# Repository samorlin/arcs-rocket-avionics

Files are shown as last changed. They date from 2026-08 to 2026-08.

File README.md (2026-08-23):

# ARCS Rocket Avionics System & Flight Computer

Custom-designed, multi-sensor flight computer and high-g avionics bay built for the UK ARCS National Rocketry Competition. Led a 4-person avionics sub-team through complete system lifecycle: prototyping, PCB layout, firmware development, mechanical structural integration, and post-flight failure analysis.
<table border="0">
  <tr>
    <td align="center">
      
      <br>
      <sub><b>Initial Prototype</b> — Sensor suite breadboard</sub>
    </td>
  </tr>
</table>

---

## Technical Specifications
* **Microcontroller:** ESP32 (3.3V logic)
* **Sensors:** BMP390 Barometric Altimeter (I2C), MPU6050 6-Axis IMU (I2C), u-blox M10 GNSS Module
* **Data Storage:** MicroSD SPI Module logging at 100 Hz
* **Telemetry:** ExpressLRS (ELRS) 2.4GHz RF Link with independent 1S battery backup
* **Power Architecture:** 2S LiPo (8.4V nominal) stepped down via high-efficiency 3.3V switching buck regulator
* **Airframe Diameter Envelope:** <40 mm ID
<table border="0">
  <tr>
    <td width="50%" align="center">
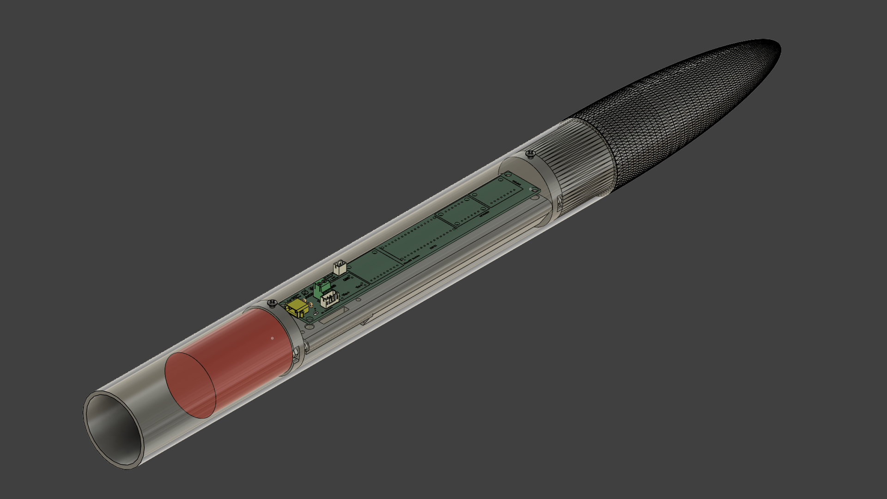
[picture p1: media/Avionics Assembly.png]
      
      <br>
      <sub><b>CAD Assembly</b> — Avionics bay & hardware stack</sub>
    </td>
---

## Key Hardware & Software Accomplishments

### 1. Custom 2-Layer PCB Design (KiCad)
* Designed a custom 2-layer FR4 board featuring dedicated ground planes to isolate sensitive I2C sensor traces from power supply EMI.
* Optimised trace routing and space efficiency to meet 40mm diameter envelope.
* Replaced low-vibration-tolerant Mini Tamiya power connectors with high-reliability XT30 connectors.
<table border="0">
  <tr>
    <td width="50%" align="center">
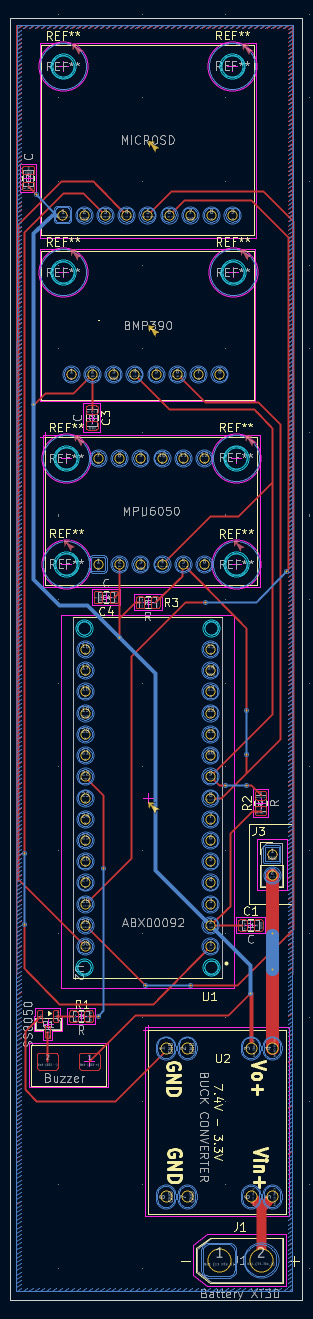
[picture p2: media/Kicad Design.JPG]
      
      <br>
      <sub><b>Initial PCB Design</b> — Unnecessary pull-up resistors and decoupling capacitors and too wide</sub>
    </td>
    <td width="50%" align="center">
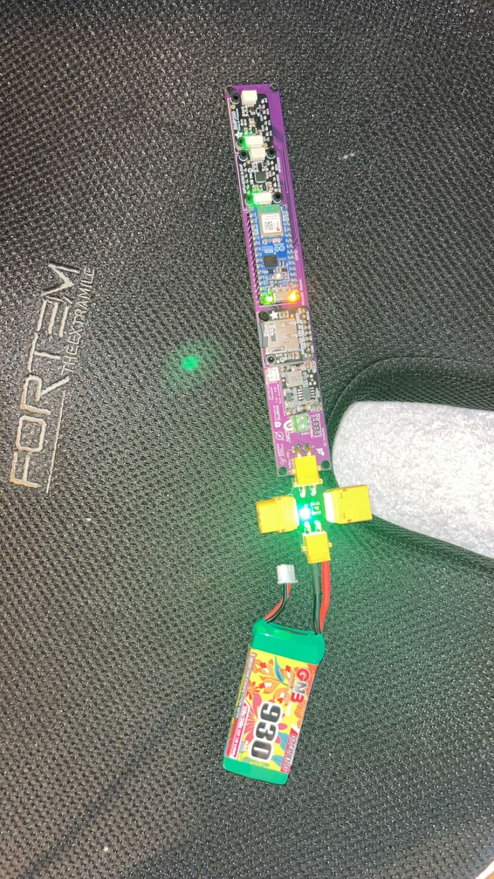
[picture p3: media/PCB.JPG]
      
      <br>
      <sub><b>Final Assembly</b> — Optimised tracing and stable power delivery and thinner package</sub>
    </td>
  </tr>
</table>

### 2. Mechanical Integration & Structural DFAM
* Designed a 3D-printed PETG sled featuring embedded brass heat-set inserts for secure, repeatable PCB mounting.
* Ran continuous M3 stainless steel load-bearing rods with Nyloc nuts through the sled assembly to absorb longitudinal shock forces during parachute deployment and ground impact.
* Designed battery mounting solution into the sled and added insert holes for live telemetry and LCD circuit.

### 3. Data Pipeline & Telemetry
* Developed C++ firmware for high-rate sensor sampling and continuous CSV write protocols.
* Created a Python script to push log data automatically into a MySQL database for MATLAB post-flight analysis and trajectory simulation.

---

## Flight Outcome & Crash Survivability Test
During competition testing, the vehicle achieved a measured apogee of 411 m. Due to a mechanical recovery wadding jam, the airframe failed to separate, resulting in an un-deployed ballistic descent hitting the ground at **80 m/s (~180 mph)**.

* **Result:** While the outer airframe and nosecone suffered heavy structural failure, the internal PETG sled and load-bearing steel rods fully protected the internal electronics.
* **Data Status:** The PCB remained intact, powered on, and actively logging. **100% of flight log data was recovered uncorrupted.**
<table border="0">
  <tr>
    <td width="50%" align="center">
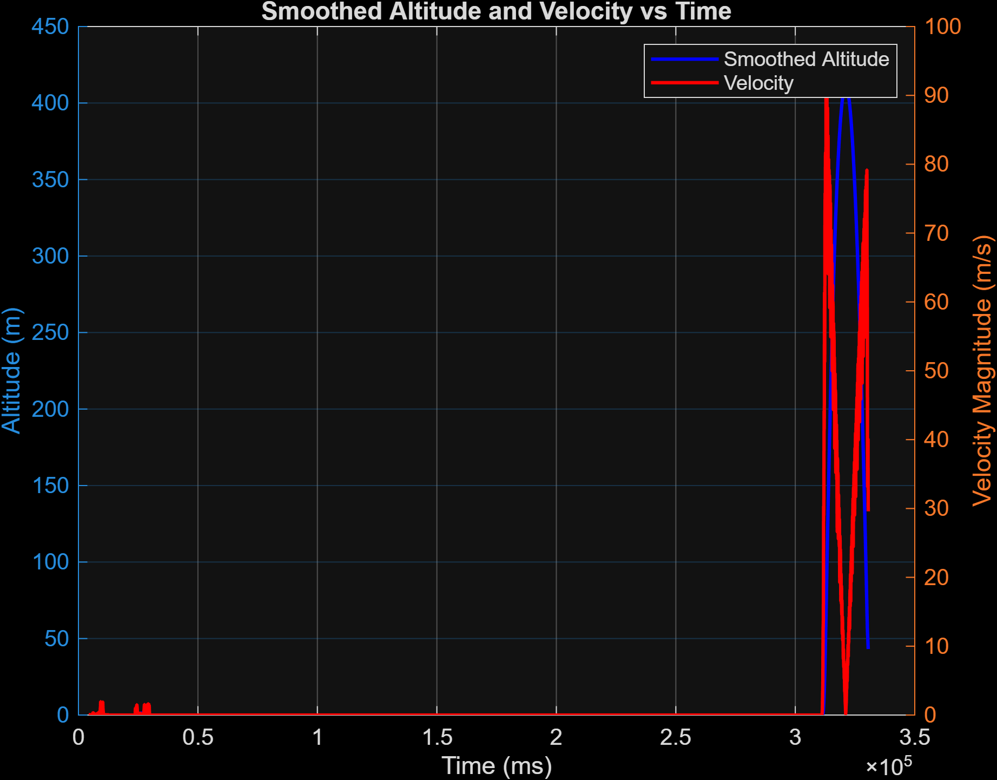
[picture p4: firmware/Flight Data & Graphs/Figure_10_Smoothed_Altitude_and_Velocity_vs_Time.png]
      
      <br>
      <sub><b>Altitude vs Time </b> — Graph shows 80m/s impact.</sub>
    </td>
    <td width="50%" align="center">
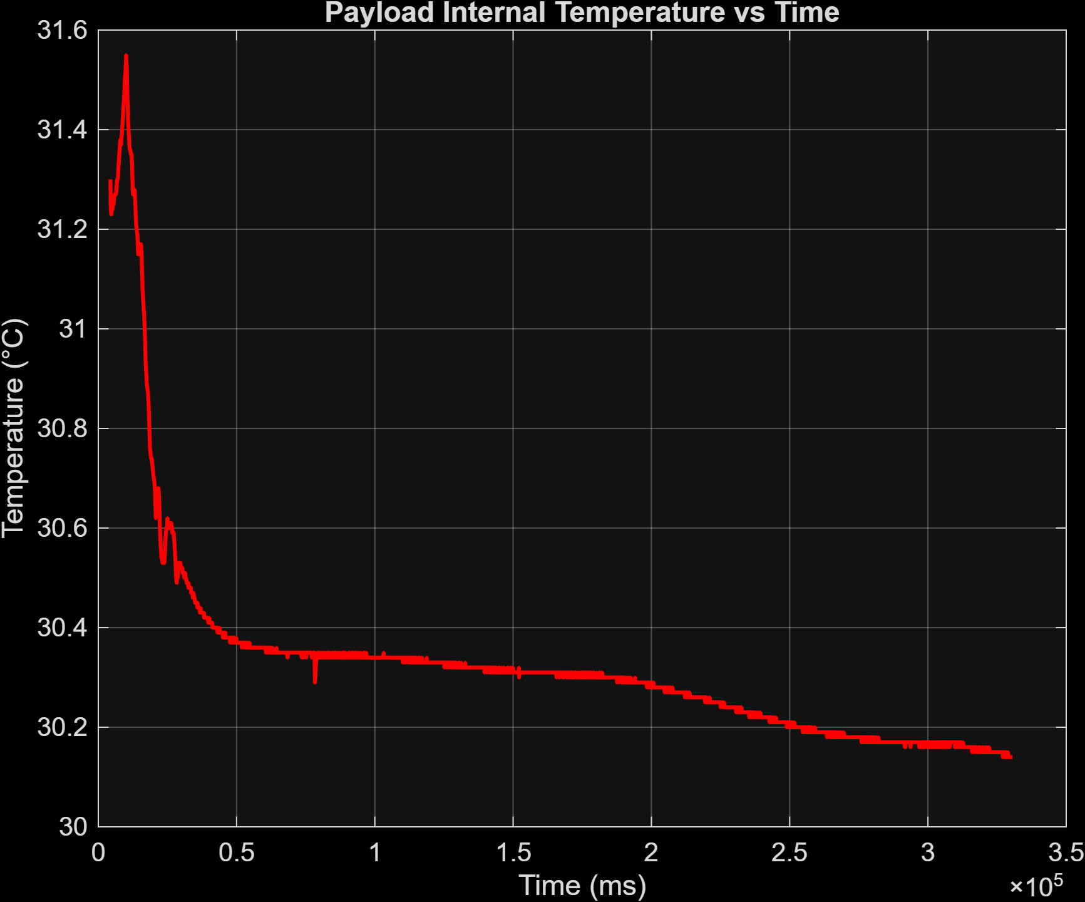
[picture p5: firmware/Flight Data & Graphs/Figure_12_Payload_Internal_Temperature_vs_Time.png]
      
      <br>
      <sub><b>Temperature vs Time</b> — Graph shows internal temperature spike when avionics powers on.</sub>
    </td>
  </tr>
</table>
---

## Repository Contents
* `/documentation/` - Formal milestone review PDFs (Critical Design Review, Manufacturing & Testing Review, Flight Readiness Review, Post-Flight Analysis).
* `/hardware/` - KiCad schematics, board layouts, Gerber files, and Full Avionics CAD Assembly (STEP).
* `/firmware/` - ESP32 C++ flight code, MATLAB scripts, raw sensor data csv and MATLAB plots.
* `/media/` - Hardware photos, PCB assembly images, Launch day photos, and post-flight recovery photos.

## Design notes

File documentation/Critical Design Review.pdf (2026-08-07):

# Critical Design Review

## Electric dysfunction Arcs Team 1

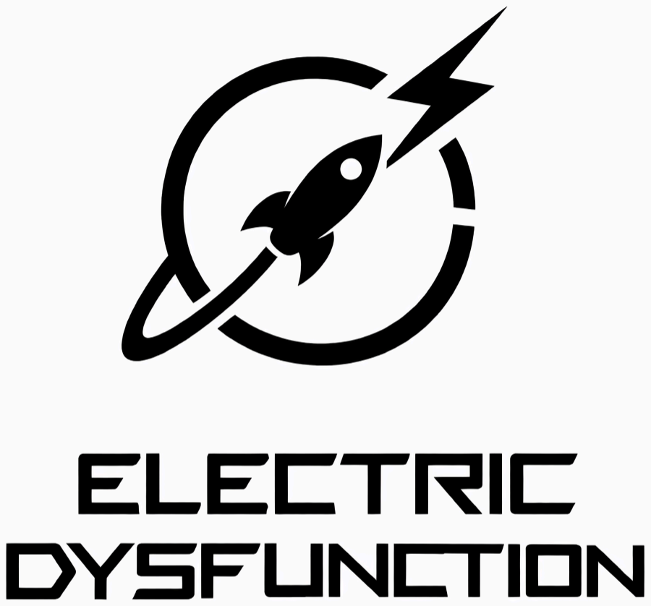
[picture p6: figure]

# Contents

# Team structure

The Team consists of 14 members which have been split into 2 sub-teams; structures and avionics. Team Lead and Vice Team lead were decided through a vote at the start of the project. Once the 2 sub-teams had been decided, each team individually voted for a team lead to over-see each side of the Rocket’s design process. All team-leads can communicate with each other to gauge the pace of the project, identify new tasks, discover any problems and assign work to other members of the team. Additionally, there is now a vice structures lead to help with better communication and organisation within the structures sub-team.

# Aims and objectives

An initial set of objectives was provided that the rocket must meet in terms of its structural aspects, avionics, and presentation. The main aim of our design was to design a rocket that would successfully launch with an impact speed between 7 and 10 metres per second, with a successful recovery system (the rocket should return in a re-launchable state), and a target altitude of 1900-2000ft. In addition to this, the payload should be at least 150 grams, collect at least 4 different types of data and should be able to successfully power itself for 40 minutes.

Name | Role | Lead | Assignment
Sam Orlin | Avionics | Avionics team lead | Hardware
Finn Woolley | Avionics | | Data processing
Alistair Wye | Avionics | | Software
Charlie sims | Avionics | | Avionics bay & Integration
Olivia Gransden | Structures | Team lead | Organisation
Lara Burke | Structures | Vice team lead | Communications
Louis Goodwin | Structures | Structures team lead | Open Rocket design
Lewis Cairns | Structures | | CAD design, Materials Research
Sophie Shandley | Structures | | Research
Dan Hubbard | Structures | Vice structures lead | Open Rocket design
Robert Seddon | Structures | | Research
Freddie Kendall | Structures | | Simulations
Tyler Cain | Structures | | Research
James Barnet | Structures | | Research

# Budget and finance

Initially, each team member contributed £10 towards our equipment costs (£140 in total); however our current budget listed below exceeds this. The team is currently discussing a potential sponsorship to cover some of the costing, however this is yet to be confirmed. Alternatively, an additional contribution of approximately £5 from each team member will support the remainder of the finances. The motor (G78-7) that was selected was funded by the ARCS competition, therefore there was no cost attached to it on our behalf as well as the nose cone being 3D printed in the IForge so there is no cost attached. The diagram below shows the current progress of purchasing the different aspects of the rocket, separated into structures and avionics. The current cost of the rocket is approximately £187 including any shipping and VAT charges.

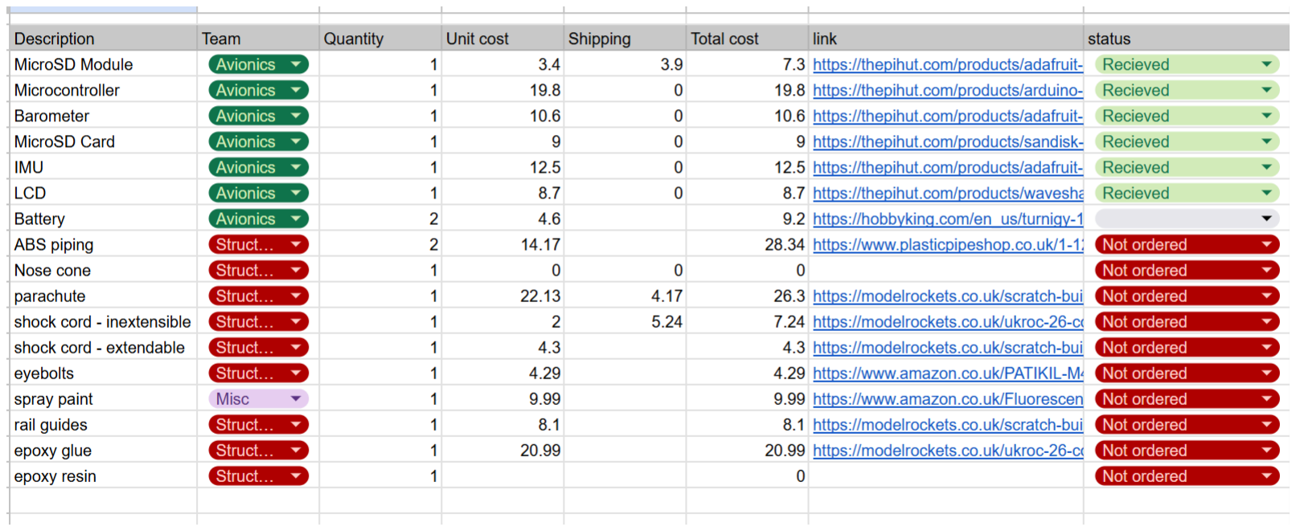
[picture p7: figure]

# Timeline

## Avionics

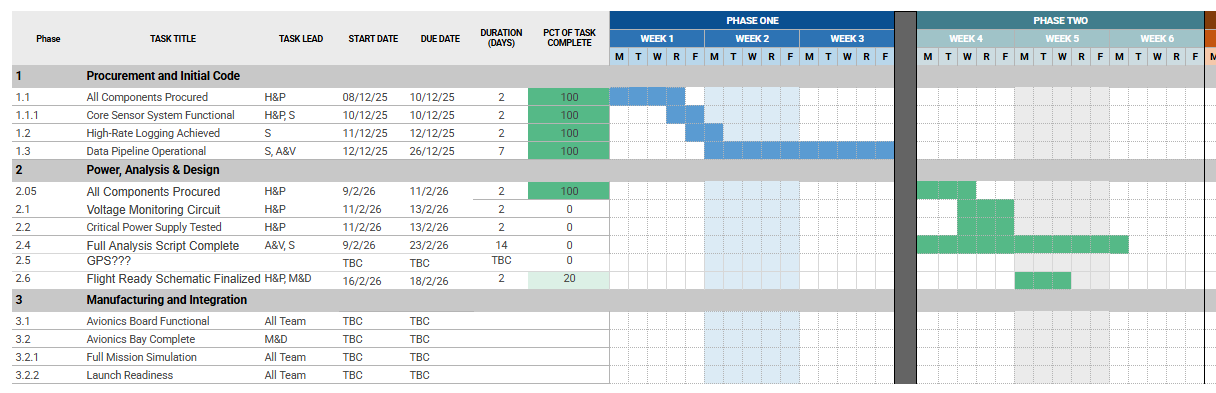
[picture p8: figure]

The avionics timeline has successfully transitioned from Phase 1 (Procurement and Initial Code), where 100% completion was achieved for high-rate logging and data pipelines by late December, to Phase 2 (Power, Analysis & Design). Currently, most hardware components are procured, our breadboard prototype is functioning and the project is focused on Power supply, voltage regulation and the critical 3.3V/1.5A Power Supply for the committee payload. While the KiCad Schematic and PCB Layout are currently in progress to meet the February 21st CDR deadline, the project remains aligned with the overall Gantt chart due to the early completion of software milestones, ensuring a sufficient buffer for the upcoming Manufacturing and Mechanical Integration phases in March.

## Structures

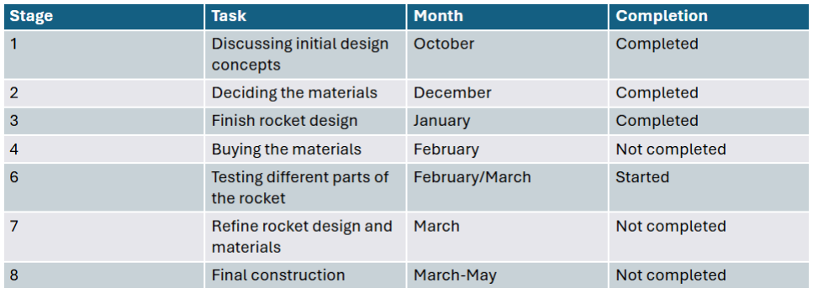
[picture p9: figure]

The structure's timeline is on track, after receiving the feedback from the PDR there have been many aspects changed in the OpenRocket design and therefore the CAD model in response to this and the design is now finalised. The next step, this month, is to start buying the materials needed such as the ABS and plywood as well as testing the forces that will be acting on the rocket. The testing will start with the nose cone being 3D printed and finding out whether it can withstand the impact force. After purchasing the materials, the other elements such as the fin roots, the shock chord will then be tested. After this the design will be refined depending on the results of the testing and the final construction will then take place.

# Design breakdown

## Launch vehicle design

The rocket has been designed with strength and structural integrity in mind. We decided to opt for a high power motor in order to challenge ourselves, as the higher the motor power rating, the more structurally sound the rocket has to be due to the greater forces the motor will exert.

In order to accommodate this, we researched extensively into what different kinds of materials could be used for all aspects of the rocket. We researched wood, plastics, cardboards and composites for each component to see which one had the properties that best suited our criteria. Those criteria were to be as lightweight as possible whilst being as strong as possible.

For the main body of the rocket, we have decided to use Class C ABS piping with an outer diameter of 48.3 mm, an inner diameter of 42.7mm and has a wall thickness of 2.8mm. We are aware that less than 3mm is not ideal for the structural integrity of the rocket, especially with such a high powered motor, however we opted for this one because it was the thickest and strongest piping we could get that would allow us to actually fit the 40mm diameter payload inside the rocket. This was actually our second choice for tubing, as we initially intended to use Class E ABS piping which is more costly but is much thicker than the Class C, however its inner diameter was marginally too small to fit the payload inside, so we had to change it. We were also debating about using Polycarbonate for the main body tubing as well due to its very high strength, however decided against it as it was around double the price and we deemed that the performance increase compared to the price increase was not worth it.

For the nose cone, we were again, initially planning on using a Haack series ABS nose cone we had found that fit the diameter of our initial Class E tubing, however with the change to our tubing we had to rethink our decision. In the end, there was no nose cones at all, let alone Haack series ones, that fit the inner diameter of our tubing, so we decided to 3D print our nose cone, so we transferred the nose cone we had designed initially into the newly updated one to fit the new apogee requirement and then got that ready for 3D printing. However, again, due to the newer, lighter tubing our apogee got increased so we needed to redesign our nose cone from scratch to reduce our apogee, as it was too high and exceeded the required 609.5 m. We did this by changing to an ellipsoid nose cone as it is less aerodynamically efficient and so would lower our apogee. This then had to be redesigned in fusion as well to be 3D printed which posses advantages as it is considerably cheaper than buying a nose cone as every member has £10 of credit to use in the IForge so we don’t need to actually spend anything for it.

For the fins, we just made them whatever shape permitted us to remain within the 1.6-2.2 stability range that the requirements state. They will be made from plywood as it is much sturdier than any of the other woods we would have available (such as balsa or cork). Whilst some woods like some types of spruce wood may have been a good option, it was considerably harder to source, especially in the dimensions we needed it to be in and far more expensive. Another major advantage of the plywood is that it is very easily accessible as it's available in the IForge and has the same cost benefits as the 3D printed nose cone.

For the shock chord, we debated using a Kevlar shock chord for our rocket, however we decided against it because it wasn’t elastic enough and wouldn’t stretch as much as we would need it to. Also, it was heavier and more expensive than the materials we actually used, which were a combination of 2 materials. We initially used just HMPE 12 as it was lighter and more extensible than the kevlar shock chord. However we found that it may still rip the bulkheads out by not being extensible enough, so we decided to add a rubber part to it to dampen the shock and lower the forces on the bulkheads so it doesn’t wrench them out.

Lastly, for the bulkheads we just decided to use balsa as we can cut it easily into the specific shape and diameter we would need. Also, again, balsa is readily available in the IForge which reduces our costs.

## Operations during flight

Once the rocket has taken off from the launch station, it should be a relatively straightforward flight assuming there are no hiccoughs in any of the systems and the weather is good. This is because the rocket will have a motor that will be active for a certain amount of time and then turn off and that should be about all of the systems that will actually affect the flight going up. The rocket should hopefully reach its maximum altitude after around 12 seconds of flight and the motor should have stopped burning shortly beforehand.

The recovery device (the parachute) will be set on a timer from when the motor is ignited and then will deploy a set time after this, after the 2 parts of the rocket have separated. We are aiming to have the parachute deploy just a few seconds after the apogee has been reached to bring the rocket down to hit the Earth with a ground speed of about 8 meters per second.

During flight an Inertial Measurements Unit (IMU) will record the acceleration and rotation in 3 axes. A BMP390 barometer will record the temperature and altitude. The altitude will be displayed on a PCB display so our apogee can immediately be verified without the need for a computer.

## OpenRocket simulations

Our goals for the ARCS include reaching a maximum apogee of 610 m while attempting to keep the flight of the rocket as stable as possible as well as safe to fly. In addition to this we also wish to ensure the rocket hits the ground at a speed which means it will be recoverable.

Based on the simulations for the most recent and up to date design for the rocket which took place with a windspeed of 10 knots, the most updated rocket designs has a velocity off rod of 14.3 m/s. This is good because it was relatively high compared to other simulations run with other rocket designs. A higher velocity here will allow for the rocket to correct itself aerodynamically through the fins earlier on in the flight, minimising the effects of any sidewinds. This allows for a straighter flight which will be more efficient and help us reach the target height easier without having to adjust any calculations. It also reached an apogee of 674m. We feel like this is a suitable height due to the tendency of OpenRocket to overestimate the apogee by around 10%. This would give us an apogee of 606.6 which is very close to the target of 610.

We also feel like this design is suitable as it has a stability of 2.03 calibers. We feel like this is ideal because it means the center of pressure is just over two body diameters behind the center of gravity, providing a strong but not excessive restoring force for stable flight. If stability was too much lower than this, then the rocket wouldn’t have a smooth take-off as well as ascent. Especially if there is wind on the day, this would mean the rocket is prone to being blown off course. If the rocket was too stable, it would make it prone to
weathercocking so stable, steady flight would once again not be achieved.

The simulation also shows the rocket will hit the ground at 7.98m/s, which will mean the estimated impact energy is around 33J which, although remains within the toughness of ABS which is what the body and nose are made from, there are concerns about damage to the fins and the nose cone depending on how the rocket lands. We need the impact velocity to be between 7-10 m/s to help with recovery of the rocket. If it was too slow coming down, any winds could blow it miles away. Given the materials that we can find for a reasonable cost, we will have to leave the dimensions of the rocket as they are in order to ensure that all the parts of the rocket fit together without causing too much complication. As a result, we are unable to have thicker walls to protect the rocket any more on impact.

The optimum delay is the time between motor burnout, which can be seen in the figure, and the parachute ejection which occurs at the apogee. The simulation gave an optimum delay of 9.75s. This time will prevent the shock cord from tearing through the body tube so is an important safety factor

The graph shows one of the simulations run on this model. It gives an overview of the estimated vertical motion over time. It shows the motor will burn out at an altitude of around 160m. Here, the rocket will have reached a suitable velocity to reach the required apogee while balancing the forces of gravity and drag.

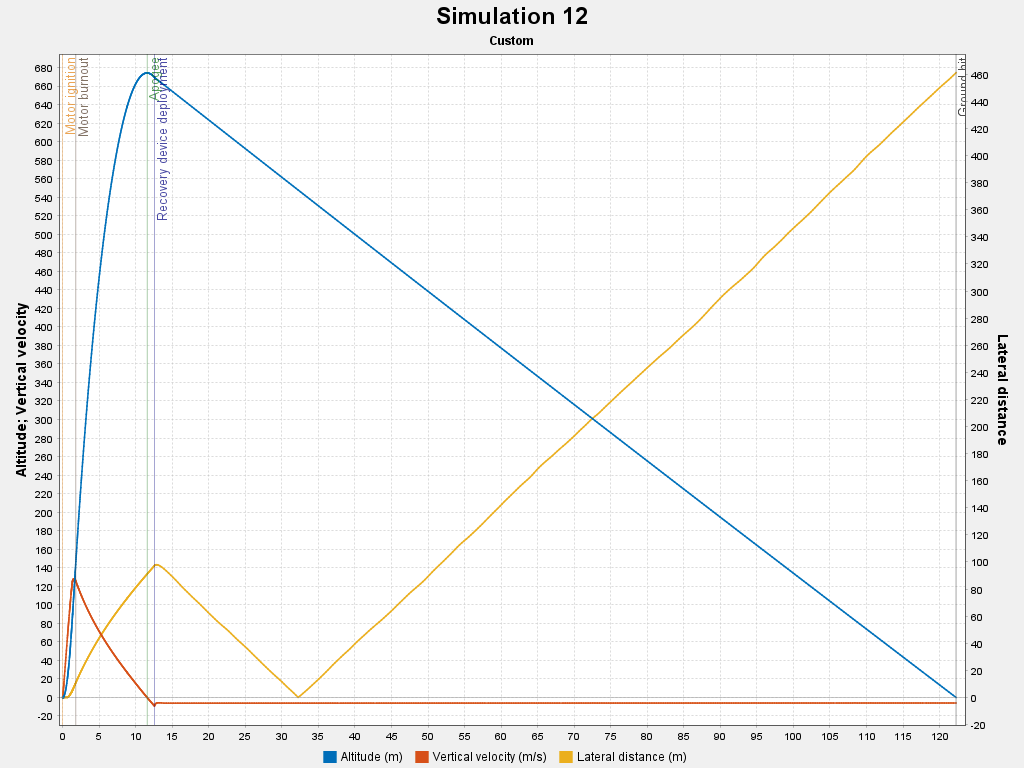
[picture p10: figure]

The graph also shows the rocket will reach a maximum lateral distance of around 460m. This would be once the rocket has landed, which is good because it won’t have travelled too far away so it will be recoverable.

## Recovery system

We have decided to use a laser-cut plywood bulkhead to provide a structural barrier between the recovery bay and the avionics bay. We chose plywood as it offers a good balance of stiffness and strength whilst also being easily manufacturable. The bulkhead will also carry the parachute and the attachment point for the shock cord.

Our rocket will use a nylon parachute recovery system designed to deploy on a timer shortly after apogee at a lower altitude to safely decelerate the rocket and return it to the ground with minimal damage. We chose nylon for its high tensile strength, durability and water resistance. The ejection charge in the motor will push off the nosecone and pull out the parachute. As the parachute inflates, the HMPE 12-strand shock cord will come under tension and absorb the loads between the rocket body and the parachute, ensuring a stable descent.

Once deployed, the nylon canopy will provide sufficient drag to reduce the rocket’s descent to a safe landing speed.

## Payload Data Analysis

The aim for the payload is to accurately record the altitude, orientation and acceleration of the rocket at all stages of its flight. This will be done by collecting several types of data and combining through MATLAB to calculate an accurate reading of the altitude and displacement of the rocket. The payload will record the current types of data:
- Altitude
- Acceleration
- Pitch, roll, yaw
- Temperature
The orientation of the rocket will be presented through a simulink model where the pitch, roll and yaw data will be used as inputs to display the orientation of the rocket as it progresses through its flight. The altitude data will be presented in a simple 2D graph against time whilst the acceleration data will be shown in 3D to show the components in all 3 axes. The question the data will answer is how does temperature vary with altitude. We hope to see a strong linear relationship between the two variables. This will be presented in a 2D graph with temperature laying on the x axis and altitude on the y axis.

Data will be logged using the Arduino using a C++ program that takes the raw data from the sensors and places them into a csv file stored on the SD card. The data to be recorded will be formatted in a database by taking the csv filevalues from the Arduino and using a python program to add these into the database using MySQL. This is done to create an easy to use, reusable piece of software and allows the data to be quickly and easily accessed in MATLAB, or any other programming language that may be used.

## Circuit diagrams & PCB Design Overview

The prototyping phase began with a full breadboard assembly to validate the electrical compatibility of the Arduino Nano ESP32 [13] with the sensor suite. To facilitate real-time debugging without needing a laptop connection on the field, we integrated an I2C LCD Screen into the prototype to align with ARCS-SOR-3-1-3. The system utilizes a shared I2C bus to interface with a BMP390 high-precision barometric pressure sensor [14] and an MPU6050 6-axis IMU [15] (accelerometer and gyroscope). Data is recorded to a MicroSD card via the SPI protocol [16].

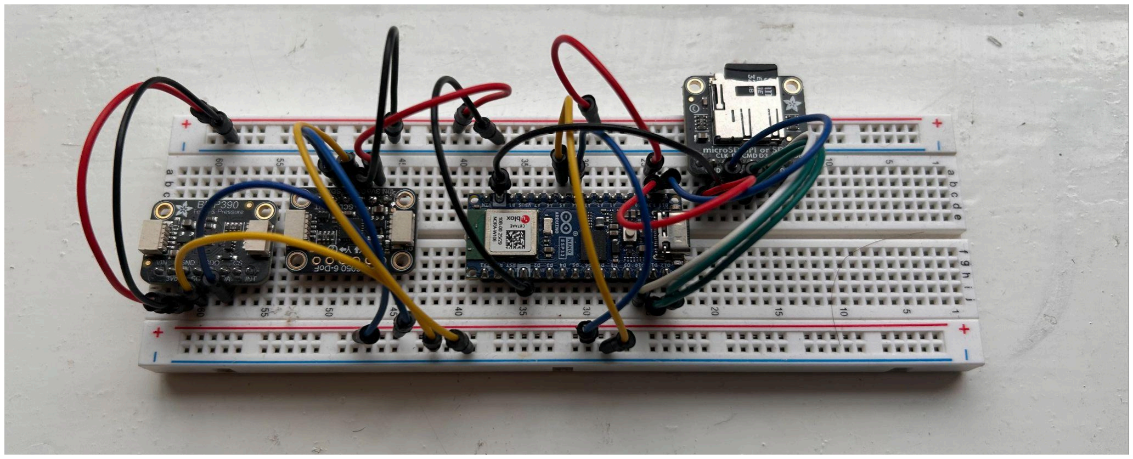
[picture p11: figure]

The PCB design is a custom 2-layer FR4 lead free HASL finish board designed in KiCad, featuring dedicated ground planes to shield the sensitive I2C signals from EMI generated by the battery [17]. Power is supplied by an 800mAh 2S LiPo battery 7.4V, which is regulated down to 3.3V via a high-efficiency buck regulator [18]. This is because the onboard voltage regulator on the ESP32 is too small and inefficient to handle the high currents required by the committee payload. This 3.3V is directed to the ESP32, which powers the sensor suite, data logger, and LCD screen. The rest of the current is diverted to the 1.5A 3.3V committee payload female JST-PH 2.0 connector.

All high-current traces are sized at 20mil or greater to ensure voltage stability during peak SD card write cycles [17]. The board is physically mounted to a PETG 3D-printed sled using M3 nylon standoffs, ensuring mechanical isolation from the airframe's primary structural loads.

The design includes 4.7kΩ pull up resistors and 0.1μF decoupling capacitors to ensure a smooth 3.3V logic level for all components[19][20]. We mitigated predicted brownouts by integrating a 10μF tantalum decoupling capacitor directly on the 3.3V rail [21], which has a lower ESR than standard electrolytic capacitors, allowing stored energy to be dumped faster, perfect for the SD module spikes. We originally planned to use GPS [22] to help recover the rocket, however, we ran into budget issues as we required a GPS module and multiple receivers and transmitters for the rocket and ground station [23][24], as well as concerns

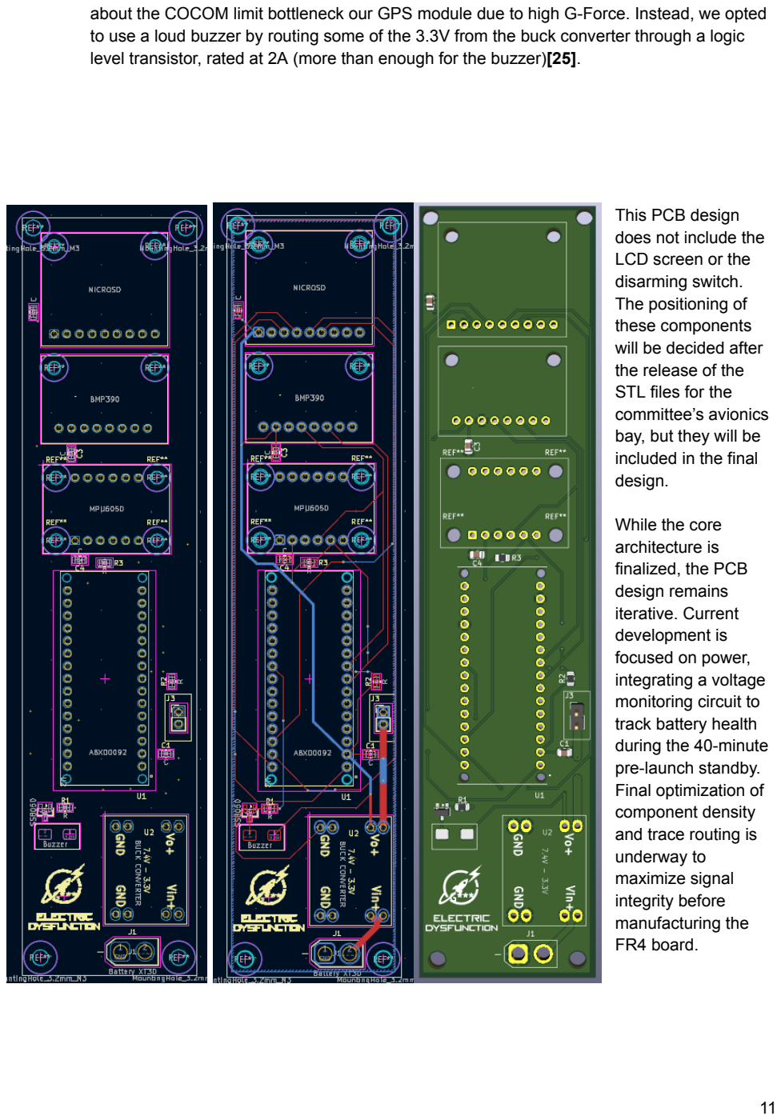
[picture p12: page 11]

about the COCOM limit bottleneck our GPS module due to high G-Force. Instead, we opted to use a loud buzzer by routing some of the 3.3V from the buck converter through a logic level transistor, rated at 2A (more than enough for the buzzer)[25].

This PCB design
does not include the
LCD screen or the
disarming switch.
The positioning of
these components
will be decided after
the release of the
STL files for the
committee’s avionics
bay, but they will be
included in the final
design.

While the core
architecture is
finalized, the PCB
design remains
iterative. Current
development is
focused on power,
integrating a voltage
monitoring circuit to
track battery health
during the 40-minute
pre-launch standby.
Final optimization of
component density
and trace routing is
underway to
maximize signal
integrity before
manufacturing the
FR4 board.

## CAD

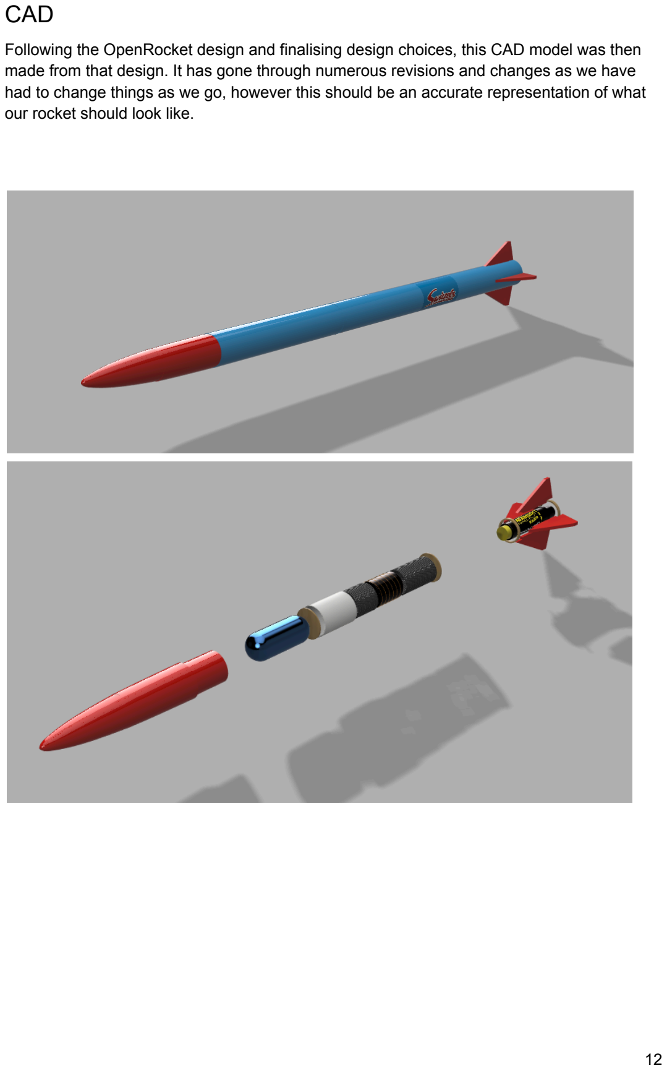
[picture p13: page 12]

Following the OpenRocket design and finalising design choices, this CAD model was then made from that design. It has gone through numerous revisions and changes as we have had to change things as we go, however this should be an accurate representation of what our rocket should look like.

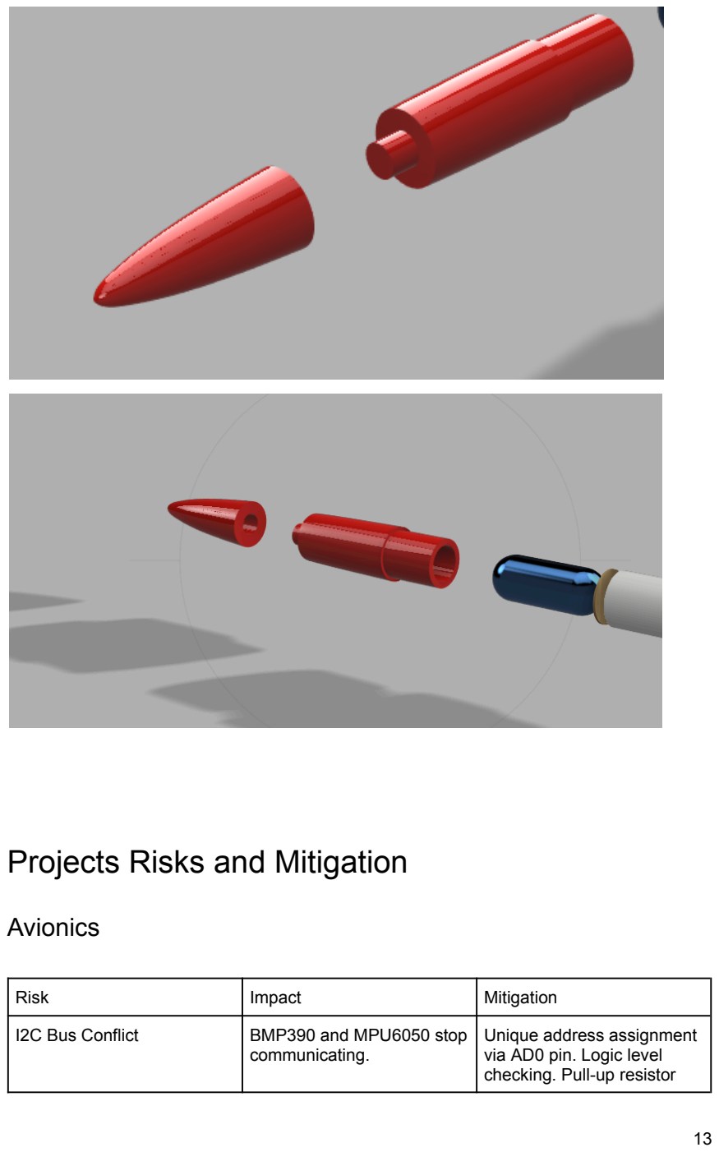
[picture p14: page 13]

# Projects Risks and Mitigation

## Avionics

Risk | Impact | Mitigation
I2C Bus Conflict | BMP390 and MPU6050 stop communicating. | Unique address assignment via AD0 pin. Logic level checking. Pull-up resistor

| | verification.
High-G Data Corruption | SD card disconnects or stops writing during launch. | Use high-speed Class 10 cards. Implement buffered writes. SD card secured with mechanical clip.
Battery Failure/Short | Total loss of power and data, potentially frying components. | Use a smokestopper when first powering the circuit. Fuse next to LiPo. Verify all solder joints under magnification.
Vibration-induced Failure | Solder joints or headers crack under flight loads. | Use through-hole components where possible; apply hot glue to secure large modules to the PCB.

## Structures

Risk | Impact | Mitigation
Shattering on impact | The rocket is then not ‘reusable’. | Reduced impact speed on the lower end of the range allowed to reduce impact force on the rocket.
The rocket body failing under the stress caused by launching | The rocket will have either structural or/and functional failure. | Perform testing on each of the elements to make sure they can withstand the forces applied.
Fins bend under the drag force. | Reduces the effectiveness of the fins and stability decreases. | Using plywood so that it has a high stiffness and strength so it does not bend due to drag forces.
The rocket being under or over stable. | The rocket will not fly straight up. | Using OpenRocket which is around 90% accurate to get our stability within the range required.

# Competition rules compliance

The rocket design has been heavily influenced by the Competition rules. Each design decision has been shaped around how to achieve the targets set by the rules. The following table shows how our rocket complies with each of the Competition rules.

## Structures

Specification | Requirement | Compliance
ARCS-CR-1-4-1 | Teams must use safe practices when building their rockets. Construction on rockets should be done using the proper equipment and spaces such as those available in the iForge | The 3D printed nosecone will be manufactured in the IForge, as well as the laser cut components such as the bulkheads and the centring rings. Assembling the rocket will require use of epoxy glue [11], so to minimise risks and danger, this will be carried out in the IForge.
ARCS-CR-1-4-2 | Hazardous materials should be avoided where available. Where these materials are used they should be justified and their use should be shown to be carefully managed to prevent harm to team members | We are using epoxy glue and ABS, which can pose some health issues. However, they are less dangerous than alternative materials such as carbon fibre, and if processed in a well-ventilated area (the IForge) the risk should be minimised [7].
ARCS-CR-1-5-1 | All motors for competitions must be ordered and purchased through the committee | The motor has been ordered by the committee
ARCS-CR-1-5-2 | All motors and explosives must be stored following UKRA guidance. | The committee are storing the motors
ARCS-CR-1-6-1 | Teams are not expected to complete test launches | No test launches are being carried out
ARCS-CR-1-6-2 | Where recovery testing does not require separation testing, teams may be able to complete this testing independently, such as with mechanical systems. Please contact the committee for guidance. | No recovery testing will be needed - the charge in the rear of the motor will be used to deploy the recovery system

ARCS-CR-2-1-1 | Rockets must not be designed to be intentionally unstable or understable. This will be defined within this competition of having a static margin of between 1.6 and 2.2 on the launch rail | Our stability is 2.03 cal [Appendix 4], which is within the stability margin requirements
ARCS-CR-2-1-2 | Rockets must have a length that is: no greater than 20x the width of the rocket/ no smaller than 10x the width of the rocket | Our rocket is 940mm in length, with a 48.3mm diameter. This means the rocket has a length:diameter ratio of 19.46:1, which is within competition regulations
ARCS-CR-2-1-3 | Rockets shall sag no more than 1% of their total length when suspended from both ends | This will be tested to verify.
ARCS-CR-2-1-4 | Any aerosurface, such as fins, must not deflect greater than 10 degrees measured across their span (root to tip) when the total flight mass of the rocket is suspended from their tip (point of maximum distance from the body) | This will be tested to verify.
ARCS-CR-2-1-5 | Motors should be mounted exclusively on the centre line and should be directed entirely through the centre line of the rocket throughout the entire flight regime | This will be ensured in our rocket by using centring rings to place the engine mount in the centre of the rocket and absorb the force applied from the thrust
ARCS-CR-2-1-6 | Fins should be able to take a force equal to (2x Fin mass x Maximum G force) suspended from their tips, pulling downwards | This will be tested to verify.
ARCS-CR-2-1-7 | All tube couplers must be a minimum of 2 diameters long, with each side of the connector extending a minimum of 1 diameter into its receiving body tube | Our tube coupler is 100mm in length, which is over the required 96.6mm.
ARCS-CR-2-1-8 | All rockets must be equipped with 6mm rail guides. There must be a minimum of two independent rail guides that align the rocket to the rail at launch, rail guides may not be detached during flight | Two 6mm rail guides have been positioned on the body, and will be screwed on through the body to prevent them falling off during flight.
ARCS-CR-2-1-9 | Rockets must not deploy components or sub-assemblies during flight. All launch | The 2 rigid launch components have been attached together by 5m of

| components must stay on the rocket. Any rocket segments that split from the rocket during recovery must be joined using a shock cord | shock cord and a nylon parachute
ARCS-CR-2-1-10 | FEA is not an accepted method of proving the strength of your rocket. Any and all load testing should be done using real components under real environments. | Structural testing will be carried out on components to ensure the rocket can withstand the required loads
ARCS-CR-2-1-11 | Rockets must not be designed to be carrying loose items or items which may cause harm if they are released from within the rocket. Any ballast must be secured in place such that it is immoveable during all phases of flight. Additionally, materials may not be placed within the recovery bay of the rocket for "aesthetics" upon deployment. (includes glitter | All parts will be fastened to each other through glue or hooks, and there will be no glitter released upon recovery deployment. D:
ARCS-CR-2-1-12 | All rockets must be designed such that they are able to be reflown (assuming that they are provided with a new motor, and if applicable recovery charges). Rockets that are not reflyable will lose points in the competition | ABS was chosen for the rocket body material over cardboard due to it being stronger [7]. This increases the survivability of the rocket and its reusability.
ARCS-CR-2-4-1 | Alternative methods to this require approval from the committee for use in the competition. Any recovery method that does not utilise the ejection charge of the motor as its primary recovery deployment MUST use a COTS flight computer for its recovery system. | Not necessary due to a single-chute recovery system being used

## Avionics

ARCS-CR-2-2-1 All teams must ensure the place is well ventilated before soldering any component. Additionally, all teams must ensure that all solder used is lead-free. All soldering performed in ventilated spaces using
lead-free solder.

ARCS-CR-2-2-2 | Before connecting a battery to your components, verify that no short circuits are present and everything is routed correctly. We suggest using a smoke-stopper when first testing avionics. Ensure that the battery is not routed to the USB port of your device. | The battery is never routed to the USB port; electrical continuity tests are in place. A smoke stopper will be used.
ARCS-CR-2-2-3 | Batteries above 7.4V are not allowed. | We will use a 2S 7.4V LiPo battery.
ARCS-CR-2-2-4 | It is recommended to use multi-core wires for signal connections. Connectors such as JST and XT are recommended as well. | Use of multi-core wiring for all flexible connections to prevent fatigue. Using XT30 connector for our battery.
ARCS-CR-2-2-5 | All teams must mechanically mount (i.e. with screws & bolts) their PCB; hot glue or epoxy can’t be used to stick your avionics to the avionics bay. PCB mounts must be designed to resist the shock forces experienced by the rocket during its flight. | Our PCB has been designed with screw holes for mounting. Our avionics bay has been designed with dampers to reduce the effects of vibration.
ARCS-CR-2-2-6 | All rockets that have electronically controlled recovery charges must have a method of externally enabling/disabling these systems via a switch and or other isolator. | The external power isolation switch is clearly labeled on the airframe.
ARCS-CR-2-3-1 -2-3-3 | Control Systems Rules | We will not use control systems in this rocket.

# Statement of requirements compliance

The rocket design has been heavily influenced by the ARCS SOR requirements. Each design decision has taken into account the SOR. The following table shows how our rocket complies with each requirement.

## Structures

ARCS Requirement | Description | Compliancy
ARCS-SOR-4-1-1 | Rockets must be reusable. | Our recovery method and

| Your rocket is expected to return in a re-flyable state. Your rocket should be designed to take all forces within its flight including impact forces without breaking. | materials used (e.g. plywood bulkhead) ensure that the rocket will only experience minimal damage, allowing it to be reused.
ARCS-SOR-4-1-2 | No free moving components. Your rocket should not have insignificant unrestrained mass. All masses should be rigidly secured to the rocket. Mass components must not be able to shift during flight | All parts are securely attached to the rocket, including the fins which are slotted into the fin tabs in the ABS piping and fastened with epoxy.
ARCS-SOR-4-1-3 | Thrust Forces must be directed into clear pathways. These pathways should be intentionally constructed to take motor forces. You are expected to justify your thrust force pathway. | We are using centering rings to connect the engine mount to the main rocket body, fastening it with epoxy resin. Because ABS is rigid, we don’t need any structural metal components.
ARCS-SOR-4-1-4 | No free falling components. All components of your rocket must return under a valid recovery method. None of your components are allowed to free-fall. | The rocket will be returned safely to the ground in one piece using the parachute, and there will be no parts separation.
ARCS-SOR-4-2-1 | Rocket decoration must be appropriate. We are launching at public sites, there will be children at launch sites. Please ensure your decorations are inoffensive and preferably apolitical. | Our rocket logo is professional. We are planning on using spray paint to create a bright and colourful design on the rocket which is appropriate for anyone viewing the rocket.
ARCS-SOR-4-2-2 | Rocket decoration must not significantly impact flight performance. Decorations should be cosmetic, with the exception of small aerodynamic changes such as body friction you should work to ensure that your decoration does not compromise the flight capabilities of your rocket. | Our decorations are purely cosmetic as we will be using spray paint, so this will not affect the rocket’s performance.

| ARCS official’s payload bay specified at 40mm in diameter | An ABS pipe with an inner diameter of 42.7mm has been selected to include this
ARCS-SOR-5-1–1 | Rockets will target an altitude of 1900-2000ft and will not exceed an altitude of 2100ft | Our Openrocket Simulations predict an Apogee of 674m (2211ft) [Appendix 4]. This has been achieved through iterative design of components such as the nosecone and the fin tabs - to not exceed the Apogee we are 3D printing our nosecone to increase the weight of of the rocket
ARCS-SOR-5-1-3 | Rockets are expected to fly in a stable manner | Our simulated stability is 2.03 cal [Appendix 4], which will provide enough stability for the rocket to be stable, whilst also minimising wind cocking
ARCS-SOR-5-1-4 | The flight data collected from the rocket should be inline with the simulations created by the teams for the flight conditions of the day. | The OpenRocket simulations are set to launch conditions with a 10kt launch speed, as specified in the documentation
ARCS-SOR-5-1-5 | Rockets must be single stage | We have designed the rocket to only have 1 motor and still reach the desired altitude. This follows the ARCS competition rules whilst also minimising design complication
ARCS-SOR-5-2–1 | Rockets must have a simulated recovery range of less than 800m from the launch site at 10kt wind speeds | From simulations of 10kt wind speeds, the simulated recovery range is 450m [Appendix 3], which is within the maximum 800m
ARCS-SOR-5-2-2 | Rockets must have a simulated impact speed of no less than 7m/s and no greater than 10m/s | Our simulated impact speed is 7.98m/s [Appendix 3], which is within the acceptable range. The way we have achieved this is by selecting a parachute that provides the desirable amount of drag for the weight of the rocket
ARCS-SOR-5-2-6 | Teams must be able to explain | We are using a 30 inch

| and justify their recovery systems throughout the project | diameter nylon parachute [3] for our recovery system. This provides a desirable amount of drag to have a suitable ground hit velocity, preventing damage to the rocket. Furthermore, nylon was selected as there is minimal friction between the material, increasing the likelihood of a successful deployment [12].
ARCS-SOR-5-2-7 | Recovery bays Must not include sharp objects, shrapnel or points which may cause harm or damage the recovery devices. | The recovery bays do not contain any sharp objects

## Avionics

ARCS-SOR-2-1-1 | Your payload should be a minimum of 150 grams. | We exceed this around (165g ATOW)
ARCS-SOR-2-1-2 | Your payload must include a custom PCB. | Custom-designed PCB integrating all flight sensors.
ARCS-SOR-2-1-3 | Your custom PCB must include a permanent imprint or etching of your team’s logo/name | Shown in PCB design.
ARCS-SOR-2-1-4 | Your custom PCB must include mounting holes for screws to mechanically secure the PCB to the avionics bay. | Shown in PCB design
ARCS-SOR-2-1-5 | Your payload must be secured and physically mounted within the rocket. | Shown in Avionics Bay design.
ARCS-SOR-2-1-6 | The avionics bays must not be pressurised. (Generally this applies to the whole rocket with the exception of the recovery bay). | The avionics bay is non-pressurized (vent holes included for BMP390).
ARCS-SOR-2-2-1 | Your payload must be capable of measuring and displaying rocket apogee. This data must also be able to be shown via a graph or | Shown in Payload Data Analysis Section,

| simulation.
ARCS-SOR-2-2-2 | Your payload should be able to power itself without issue for at least 40 minutes. | Power system validated for >40 minutes of continuous operation.
ARCS-SOR-3-1-1 | Your payload must be capable of recording at least 4 types of data. | Data logged at 100Hz in .csv format for post-flight analysis.
ARCS-SOR-3-1-1 | Your payload must be capable of recording at least 4 types of data. | We will be recording temperature, altitude, acceleration, and orientation.
ARCS-SOR-3-1-2 | Your team must have a research question related to at least one of the data points you are recording. | The question we will be answering is “how does the temperature of the atmosphere change with altitude” we will be using our temperature data to answer this.

# Manufacture methods

## Structures

Part | Material | Method
Tubing | ABS | Abs tubing will be bought online then cut down to the required lengths. Holes will be drilled where required for the payload
Nose Cone | PETG | The nose cone will be 3D printed with a 20% infill rather than purchased as we cannot find a nose cone available online to fit the dimensions of our body. It will be attached to the body via screws as it needs to be removable to access the avionics bay.
Fins | Plywood | The fins will be laser-cut and attached to the body tube via epoxy glue.
Bulkheads | Plywood | The bulkheads are laser-cut and attached to the body tube via epoxy glue.

Centering rings | Plywood | The centering rings will be laser-cut and attached to the body tube
Coupler | PLA | 3D printed
Inner tube | Cardboard
Shock cord | Elastic cord | Attached to the bulkheads via metal eyelets.
Rail Button | Delrin | Purchased and attached to boxy with epoxy glue

## Avionics

PCB
Once the PCB is finalised, and the pull up resistors, decoupling capacitors, and transistor has been soldered onto the board, it will be shipped to us, where we will solder all our sensors, our SD module, battery connectors, buzzer and microcontrollers will be mounted and soldered in their correct positions. Everything is hand soldered using flux core lead free solder[26]. Post soldering, the board is cleaned with IPA to remove residual flux, which can become conductive in high humidity launch conditions[27].
Avionics Bay
The avionics suite will be housed on a 135x38.5mm single piece of 3D printed PETG, selected for its thermal stability [28] to withstand pre-launch standby periods (ARCS-SOR-2-2-2). This sled slides along dual M3 stainless steel threaded rods, which act as a structural backbone to absorb longitudinal tension during parachute deployment. The assembly is capped by 42mm birch plywood bulkheads, secured with M3 Nyloc nuts and shoulder washers to resist high-frequency motor vibrations.

To ensure data integrity under load, the PCB will be mounted on M3 nylon standoffs, while heavier components like the 800mAh battery are centered to reduce radial forces. Neoprene foam and zip ties provide secondary vibration dampening for modular sensors. The airframe will feature three 120° offset 2mm static ports [29], allowing the BMP390 to sample ambient pressure without bay pressurization (ARCS-SOR-2-1-7). Electrical safety is maintained by an arming switch mounted perpendicular to the axis of travel.

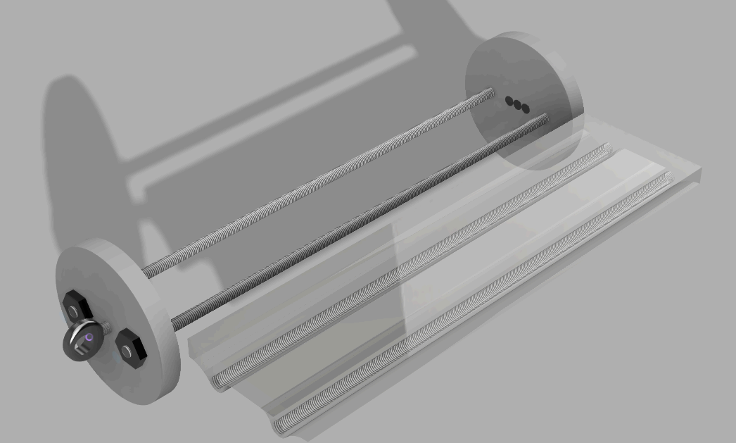
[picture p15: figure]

# Testing

## Avionics

The following 3 stage testing protocol will be implemented upon completion of the PCB Assembly. The tests are designed to validate data logging, and mitigate risks associated with the compactness of the AV bay and the high vibration environment.

Stage 1 - Electrical Continuity Test - Before the initial power-up, a Point-to-Point Continuity Test will be performed using a digital multimeter, specifically focusing on the tight tolerances around the transistor and buck converter as well as ensuring the M3 threaded rods are isolated. Finally, we will power the PCBA on via a smoke stopper, to ensure there are no shorts.

Stage 2 - Power and Thermal Testing - To satisfy ARCS-SOR-2-2-2, the system will undergo a 60-minute Endurance Test to ensure we can power the circuit for longer than 40 minutes. The avionics bay will be fully assembled and powered by the 7.4V LiPo. We will monitor the internal temperature of the enclosed tube to ensure that heat dissipation from the buck converter does not melt the PETG sled or cause thermal drift in the BMP390 altitude readings.

Stage - 3 - Simulated Flight and Environmental Stress Test - A vacuum chamber simulation will be used to validate the altimeter’s logic. We will reduce ambient pressure to simulate an ascent to the target apogee, verifying that our software correctly identifies “Launch”, “Apogee”, and “Landing” states. Finally, the assembly will be subjected to a mechanical vibration test, simulating motor thrust while actively logging data at 100Hz. We will then analyse the .csv file for any data skips or corruption, as well as confirm the structural rigidity of the PCBA.[30]

## Structures

Initial standard tensile testing will be done on the Class C ABS piping, using the Zwick Proline Z020 stress testing machines in the diamond. As we had to change the wall size to 2.8mm, we decided it was important to test if the material would still be strong enough to withstand recovery.

Once the rocket is fully assembled, we will suspend the rocket at both ends and test how much it sags, by measuring the difference in sagging between the rocket being supported at the centre of mass and with no support except for the two at each end. This is to ensure that it sags less than 1% of its total length in accordance with ARCS-CR-2-1-3. Furthermore, we will suspend the rocket with strings attached to the tip of each fin, and then use a protractor to measure the angle of deflection of the fins from the horizontal. This is to ensure that the angle is under 10 degrees as required by ARCS-CR-2-1-4. Finally, the rocket will be suspended sideways and have a hanging weight equal to double the fin mass tied to the tip of a fin. This will be tested with the fin facing both outwards horizontally and downwards.

This is to ensure the rocket meets ARCS-CR-2-1-6, with the fins being able to withstand a force equivalent to double its weight.

We also elected to do drop testing with the parachute by attaching a weight to it and dropping it from a set height, using slow-motion filming to measure the time taken to fall. This would let us calculate how much drag the parachute provides and get an experimental estimate for recovery speed. Furthermore, we decided to drop test our 3D printed nose cone to ensure it would withstand recovery. This will be done by adding weight to the nosecone to simulate the rest of the rocket and dropping it from a height that will provide a greater impact speed than on the launch day.

# Design changes from PDR

- Changed to using PETG instead of polycarbonate/ABS as we have decided to 3D print the nosecone instead of buying it from a supplier.
- Changed from using the Haack series (slide 10 on PDR) nosecone to ellipsoid as it reduces the apogee to meet the requirement and is also structurally stronger and so less likely to snap on impact, which is a bonus.
- Length of the nose cone went from 254mm to 240mm to make it easier to 3D print.
- Base diameter of the nose cone went from 48.5mm to 48.3mm to suit the new ABS pipe diameter.
- The wall thickness of the pipe went from 4mm to 5.5mm.
- The ABS pipe thickness has been reduced to 2.8mm to accommodate the avionics.
- The ABS outer diameter has been changed to 48.3mm and 42.7mm inner diameter as it is easier to find stock ABS pipes of this size and also would allow us more freedom when fitting the avionics.
- Increased the thickness to 3mm to align with the Iforge stock thicknesses.
- In the PDR, material choice was split between Polycarbonate and ABS in PDR but ended up going with ABS because of the good strength to weight ratio and the fact that it is much cheaper than the alternative.
- Added the ARCS supplied payload (based the weight off our payload) to the open rocket design to help with simulation accuracy.

# Issues Encountered and Lessons Learnt

## Structures

One issue we encountered was that our rocket’s apogee was predicted to exceed the maximum value specified. To prevent this we redesigned the nosecone, changing from a Haack Series to an ellipsoid shape to reduce aerodynamic efficiency and therefore apogee as well. We were also forced to change our tubing from class E ABS to class C ABS due to the introduction of the 40mm diameter payload which would not fit in our original choice. Another issue in one of our initial designs was the centering rings interfering with the fin tabs, however we were able to rectify this by redesigning a model with appropriate spacing of the centering rings on either side of the tabs. We also did not initially consider how the hot gas from the charge on the motor would reach the upper bulkhead. This will be solved by putting holes in the lower bulkhead allowing the gas to pass through. All of these issues required further simulations to be carried out and the creation of new models. One issue we continue to grapple with is that the majority of model rocketry components need to be shipped from America which greatly increases our costs. The team is attempting to be as prudent with our budget and deliberate with our component selection as possible to manage this issue. These issues have reminded the team of the importance of having a full understanding of all the requirements before beginning design but also the importance of continuing to remain as flexible as possible to combat the inevitable problems we will face later in the project.

## Avionics

During the development of the avionics suite, our team resolved several critical challenges as a result of the compact 43mm airframe and the rigorous ARCS competition requirements. Initially, we encountered predicted brownouts caused by high-current transients during Micro SD card write cycles, which would temporarily starve the I2C sensors of power. We mitigated this by integrating a 10µF tantalum decoupling capacitor directly on the 3.3V rail and widening the main power traces to 30-mil to ensure a stable supply. Furthermore, the tight 2.54mm pitch of our buck converter triggered Design Rule Check (DRC) clearance violations of under 0.2mm, posing a short-circuit risk during manual soldering. We resolved this by redesigning the footprint with oval pads, increasing the pad-to-pad clearance to a safe 0.3mm. Furthermore, because verified libraries for our specific SD and GPS modules did not exist, we had to meticulously build custom footprints from scratch using datasheet tolerances and digital calipers. We will validate these designs by test-fitting the physical components onto a 1:1 scale paper printout of the board before ordering the FR4, eliminating the risk of manufacturing delays. Signal integrity was also addressed. To combat parasitic capacitance and EMI degrading our I2C communication, we implemented a continuous bottom ground plane and added physical 4.7kΩ pull-up resistors to the SDA and SCL lines, securing the mandatory 100Hz logging rate (ARCS-SOR-3-1-1). Finally, to manage thermal buildup inside the sealed tube during the 40-minute pre-launch standby (ARCS-SOR-2-2-2), we utilized a high-efficiency switching buck converter instead of a linear regulator and mounted the assembly on a heat-resistant PETG sled (75°C), guaranteeing the hardware will not overheat or deform on the launch rail.

# Appendices

motor; Velocity; off rod (m/s); Apogee (m); Velocity at deploy ment; Max velocity (m/s); Max acceler ation (G); Time to apogee (s); Flight time (s); Ground hit velocity (m/s)
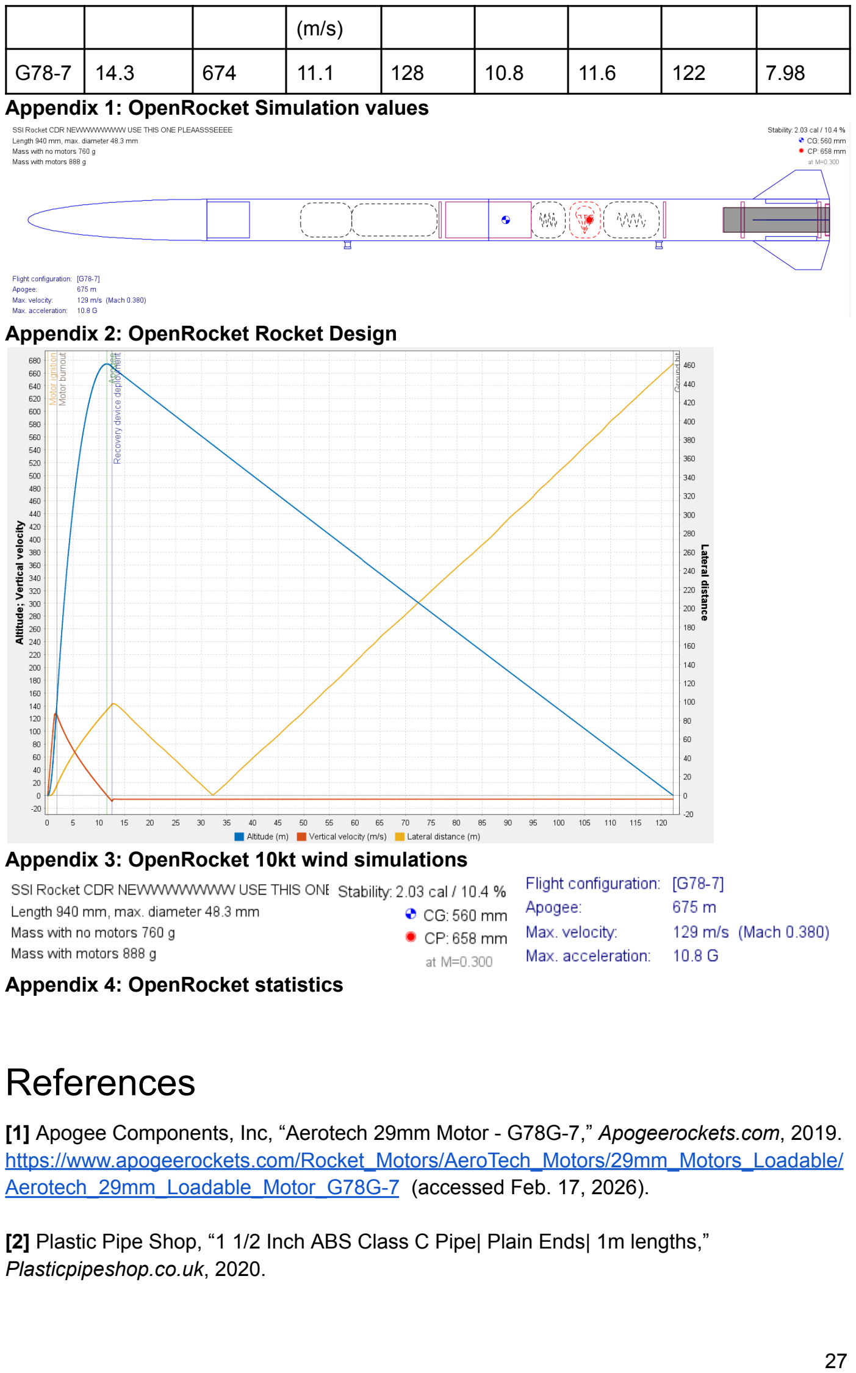
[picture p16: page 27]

| | | (m/s)
G78-7 | 14.3 | 674 | 11.1 | 128 | 10.8 | 11.6 | 122 | 7.98
Appendix 1: OpenRocket Simulation values

Appendix 2: OpenRocket Rocket Design

Appendix 3: OpenRocket 10kt wind simulations

Appendix 4: OpenRocket statistics

# References

[1] Apogee Components, Inc, “Aerotech 29mm Motor - G78G-7,” Apogeerockets.com, 2019. https://www.apogeerockets.com/Rocket_Motors/AeroTech_Motors/29mm_Motors_Loadable/Aerotech_29mm_Loadable_Motor_G78G-7 (https://www.apogeerockets.com/Rocket_Motors/AeroTech_Motors/29mm_Motors_Loadable/Aerotech_29mm_Loadable_Motor_G78G-7) (accessed Feb. 17, 2026).
[2] Plastic Pipe Shop, “1 1/2 Inch ABS Class C Pipe| Plain Ends| 1m lengths,” Plasticpipeshop.co.uk, 2020.

https://www.plasticpipeshop.co.uk/1-12-ABS-Class-C-Pipe-Plain-Ends-in-1m-Lengths_p_8277.html?_gl=1 (https://www.plasticpipeshop.co.uk/1-12-ABS-Class-C-Pipe-Plain-Ends-in-1m-Lengths_p_8277.html?_gl=1) (accessed Feb. 17, 2026).

[3] Model Rockets UK, “30" Neon pink 1.7oz ripstop nylon parachute topflight TFR standard,” Model Rockets.co.uk. https://modelrockets.co.uk/scratch-building-bits/recovery-system/parachutes/30-neon-pink-1-7oz-ripstop-nylon-parachute-topflight-tfr-standard/ (https://modelrockets.co.uk/scratch-building-bits/recovery-system/parachutes/30-neon-pink-1-7oz-ripstop-nylon-parachute-topflight-tfr-standard/) (accessed Feb. 2026).
[4] Model Rockets UK, “2mm DYNEEMA / HMPE 12-strand Rope Silver 530kg MBL Shock Cord (per meter),” Model Rockets.co.uk. https://modelrockets.co.uk/ukroc-26-competition/shock-cord/2mm-dyneema-hmpe-12-strand-rope-grey-530kg-mbl-shock-cord/ (https://modelrockets.co.uk/ukroc-26-competition/shock-cord/2mm-dyneema-hmpe-12-strand-rope-grey-530kg-mbl-shock-cord/) (accessed Feb. 17, 2026).
[5] Model Rockets UK, “Rubber Shock Cord 3mm - 1.5m Length - Klima,” Model Rockets.co.uk.
https://modelrockets.co.uk/scratch-building-bits/recovery-system/harnesses/rubber-shock-cord-3mm-1-5m-length-klima/ (https://modelrockets.co.uk/scratch-building-bits/recovery-system/harnesses/rubber-shock-cord-3mm-1-5m-length-klima/) (accessed Feb. 17, 2026).
[6] Aerospace Industries Association, “How to Build a Model Rocket,” YouTube. http://www.youtube.com/playlist?list=PLB1CABBFAA7E67039 (accessed Feb. 17, 2026).
[7] Adreco plastics, “ABS Plastic Properties | Advantages of Acrylonitrile butadiene styrene,”
Adreco Plastics, 2022. https://adrecoplastics.co.uk/abs-plastic-properties/ (accessed Feb. 17, 2026).
[8] J. Bezos, “PATIKIL M3x16mm Eye Bolts, 10 Pcs Carbon Steel Threaded Eyebolt Eye Hooks Screws with Nut for Hanging or Securing Cables Silver,” Amazon. https://www.amazon.co.uk/PATIKIL-M4x30mm-Threaded-Eyebolt-Securing/dp/B0DWXF558Z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 olts&pd_rd_i=B0DWWTNL2M&pd_rd_r=5e84db95-cfdc-49b4-b7b4-6a9f3fe620c2&pd_rd_w =ZzwwI&pd_rd_wg=EinRT&pf_rd_p=8ba64628-66cf-49a6-9610-82f6003a38ab&pf_rd_r=2N 7AWFQ2N7M41BZ2YTAW&qid=1769167693&sbo=RZvfv%2F%2FHxDF%2BO5021pAnSA %3D%3D&sprefix=model%2Brockeyebolts%2Caps%2C138&sr=1-2-fd3c5e6b-a8f7-4e24-85 ab-454044c653b9-spons&aref=cgENDwmApo&sp_csd=d2lkZ2V0TmFtZT1zcF9zZWFyY2hf dGhlbWF0aWM&th=1 (https://www.amazon.co.uk/PATIKIL-M4x30mm-Threaded-Eyebolt-Securing/dp/B0DWXF558Z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) (accessed Feb. 17, 2026).
[9] J. Bezos, “6 Cans of Fluorescent Neon Spray Can Paint 200ML Graffiti (Banksey) N0 CFCs,” Amazon.co.uk.
https://www.amazon.co.uk/Fluorescent-Spray-Paint-Graffiti-Banksey/dp/B071KL5K2C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 5GmFEH6S1eBuy1ccIcfnE8WfxkJ64SCDtbhx4c7A4lrCR2NeiNLmBPwDRXvw4TzmPQuKO zHKOJ9AFB9vgvQUaJIc1TVBxQ3JBncw5yFRAO0CD0nP1PXjZUXGxfYiysThqvP5dxg8ma PWJvj5fil3pDbUp_ToXCfGFQH6iWvS05veeN5m0jezImXPBlAdu_W3TZ64fn0XMUucWPDV d75-tfZEcGSHSSWWyuNcq4haZqlWXoPDjIx3fpCKAgRjfe9yRiZN_oxoGAKY.OXOSTVrneE (https://www.amazon.co.uk/Fluorescent-Spray-Paint-Graffiti-Banksey/dp/B071KL5K2C)

uI7fT6ta-OwGIeN1lOXesSYPdLoT9D_tc&dib_tag=se&keywords=spray+paint&qid=1769168 290&sprefix=spray+paint%2Caps%2C143&sr=8-8 (https://www.amazon.co.uk/Fluorescent-Spray-Paint-Graffiti-Banksey/dp/B071KL5K2C) (accessed Feb. 17, 2026).

[10] Model Rockets UK, “Loc precision rail guides - Series 1000 - 6 pack,” Model Rockets.co.uk.
https://modelrockets.co.uk/scratch-building-bits/launch-lugs-and-rail-buttons/loc-precision-rail-guides/ (https://modelrockets.co.uk/scratch-building-bits/launch-lugs-and-rail-buttons/loc-precision-rail-guides/) (accessed Feb. 17, 2026).
[11] Model Rockets UK, “BSI 15 Minute Epoxy 9oz (266ml) Glue,” Model Rockets.co.uk. https://modelrockets.co.uk/ukroc-26-competition/tools-glues-etc/bsi-15-minute-epoxy-9oz-266ml-glue/ (https://modelrockets.co.uk/ukroc-26-competition/tools-glues-etc/bsi-15-minute-epoxy-9oz-266ml-glue/) (accessed Feb. 17, 2026).
[12] British Plastics Federation, “Nylons (Polyamide),” Bpf.co.uk, 2019. https://www.bpf.co.uk/plastipedia/polymers/polyamides.aspx (accessed Feb. 17, 2026).

Electronics & Sensors

[13] Arduino. (2023). Arduino Nano ESP32 Datasheet and Technical Specifications. https://docs.arduino.cc/resources/datasheets/ABX00083-datasheet.pdf (accessed Dec. 2025)
[14] Bosch Sensortec. (2020). BMP390 High-performance pressure sensor Datasheet. https://www.bosch-sensortec.com/media/boschsensortec/downloads/datasheets/bst-bmp390 -ds002.pdf (https://www.bosch-sensortec.com/media/boschsensortec/downloads/datasheets/bst-bmp390-ds002.pdf) (accessed Dec. 2025)
[15] TDK InvenSense. (2013). MPU-6050 Six-Axis (Gyro + Accelerometer) MEMS MotionTracking Device.
https://invensense.tdk.com/wp-content/uploads/2015/02/MPU-6000-Datasheet1.pdf (accessed Dec. 2025)
[16] SD Association. (2023). Physical Layer Simplified Specification Version 9.10. https://www.sdcard.org/cms/wp-content/uploads/2023/10/Ver9.10PR_EN.pdf (accessed Dec. 2025)

[22]u-blox. (2023). NEO-M9N-00B: Standard Precision GNSS Module Data Sheet (UBX-19014285).
https://content.u-blox.com/sites/default/files/NEO-M9N-00B_DataSheet_UBX-19014285.pdf (accessed Dec. 2025)

[24]Semtech Corporation. (2023). SX1280/SX1281 Long Range Low Power 2.4GHz Transceiver Datasheet.
https://mm.digikey.com/Volume0/opasdata/d220001/medias/docus/483/SX1280-81_Rev3.2_Mar2020.pdf (https://mm.digikey.com/Volume0/opasdata/d220001/medias/docus/483/SX1280-81_Rev3.2_Mar2020.pdf) (accessed Dec. 2025)

[25]onsemi. (2021). NDS351AN: N-Channel Logic Level Enhancement Mode Field Effect Transistor Datasheet.
https://www.google.com/search?q=https://www.mouser.com/datasheet/2/308/onsemi_nds351an_datasheet-2313620.pdf (https://www.google.com/search) (accessed Feb. 2026)

PCB Design & Assembly Standards

[17] IPC. (2021). IPC-2221B: Generic Standard on Printed Board Design. https://pcbsync.com/ipc-2221/ (accessed Feb. 2026)

[26]IPC. (2020). IPC-J-STD-001H: Requirements for Soldered Electrical and Electronic Assemblies.
https://www.protoexpress.com/blog/ipc-j-std-001-standard-soldering-requirements/(accessed Feb. 2026)

[27]IPC. (2011). IPC-CH-65B: Guidelines for Cleaning of Printed Boards and Assemblies. https://webstore.ansi.org/standards/ipc/ipcch65b2011 (accessed Feb. 2026)

Power & Signal Integrity

[18] Texas Instruments. (2022). Understanding Buck Power Stages in Switch-Mode Power Supplies.
https://www.ti.com/lit/an/slva059/slva059.pdf (accessed Feb. 2026)
[19] NXP Semiconductors. (2021). UM10204: I2C-bus specification and user manual. https://www.nxp.com/docs/en/user-guide/UM10204.pdf (accessed Feb. 2026)
[20] Murata Manufacturing Co., Ltd. (2022). Basics of Noise Countermeasures: Decoupling Capacitors.
https://www.murata.com/products/emc/emifil/library/knowhow/basic/s2-chapter06-p1 (accessed Feb. 2026)

[21]Texas Instruments. (2020). Power Supply Decoupling and Bypass Filtering Basics (SLYF011).
https://www.google.com/search?q=https://www.ti.com/lit/pdf/slyf011 (accessed Feb. 2026)

Aerospace & Testing Standards

[23]ExpressLRS. (2025). ExpressLRS Technical Documentation: High Performance Open Source Radio Control Link. https://www.google.com/search?q=https://www.expresslrs.org/technical-details/ (accessed Feb. 2026)

[28]ASTM International. (2022). ASTM D648: Standard Test Method for Deflection Temperature of Plastics Under Flexural Load.
https://www.astm.org/d0648-18.html (accessed Feb. 2026)

[29]NASA. (1966). NASA SP-125: Design and Testing of Static Pressure Systems. https://www.google.com/search?q=https://ntrs.nasa.gov/citations/19660025214 (accessed Feb. 2026)

[30]U.S. Department of Defense. (2019). MIL-STD-810H: Environmental Engineering Considerations and Laboratory Tests. https://quicksearch.dla.mil/qsDocDetails.aspx?ident_number=35978 (accessed Feb. 2026)

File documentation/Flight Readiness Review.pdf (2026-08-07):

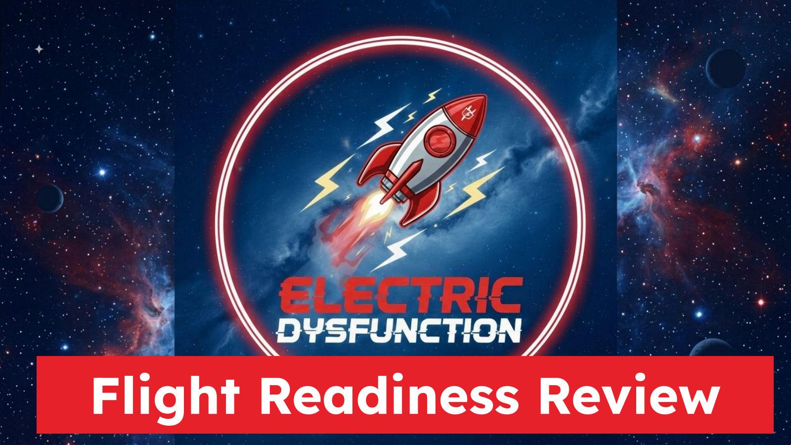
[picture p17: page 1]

# Flight Readiness Review

# Group structure and Structures project timeline

The project timeline so far shows that the rocket will be completed before launch day. Most of the assembly has been done and only has the finishing touches such as adding the logo onto the body of the rocket is left to do. The rocket is now predicted to be fully
assembled and flight ready by the end of this week.

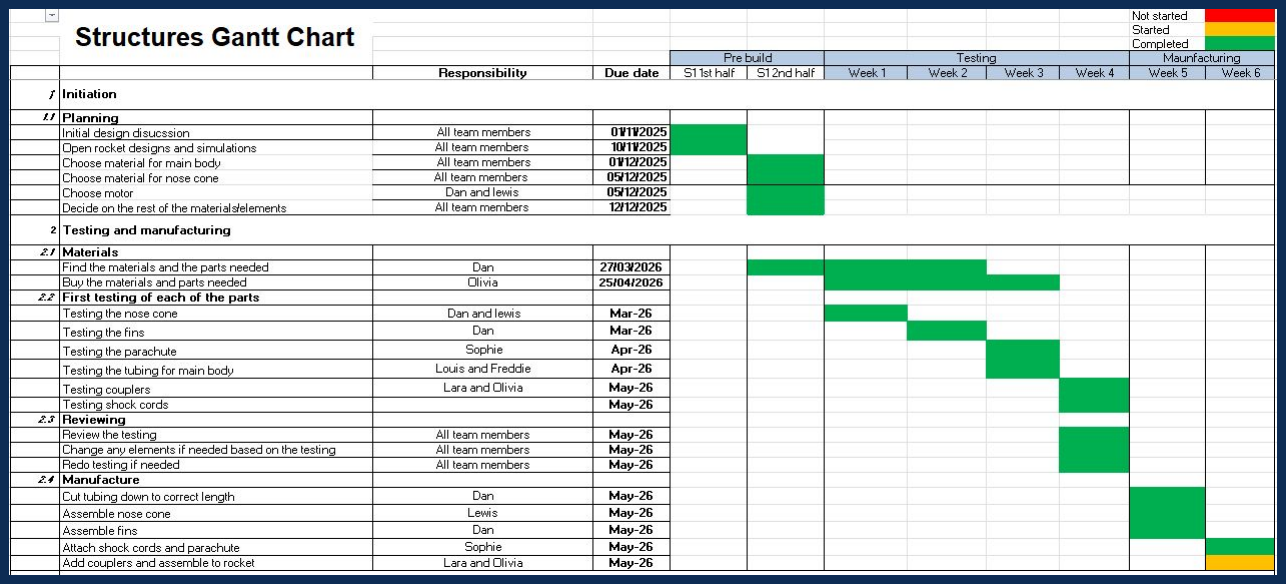
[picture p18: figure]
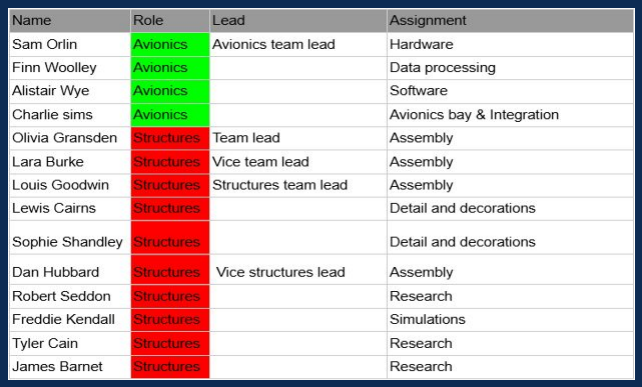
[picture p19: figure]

The team still consists of 14 members, and has two subteams avionics and structures. The team leads have stayed the same however the assignments for some of the team members have changed now that the project has moved onto the final assembly and decoration stages.

# Avionics project timeline

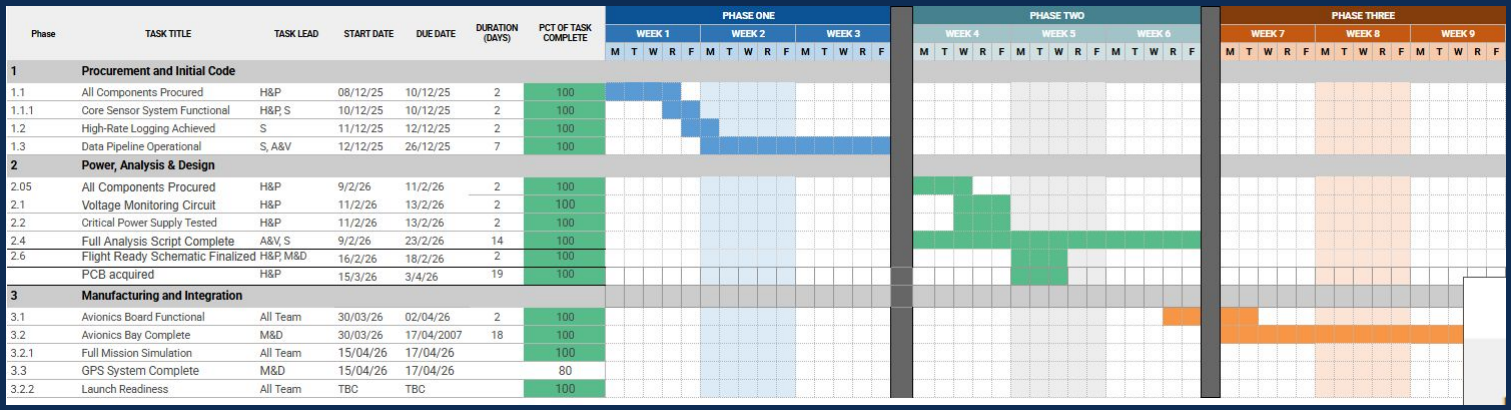
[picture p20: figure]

The avionics subsystem is near completion and on track for launch day, with all critical flight hardware successfully integrated. Since the MTR, the avionics bay has been finalized, with the PCB fully secured and mounted to the finalized 3D-printed PETG sled. The GPS system is now functional, though the ground link for the GPS coordinate system remains incomplete, and while we continue to work on it, it is considered a non-essential task for pre-flight operations and does not affect launch capability. Additionally, the LCD screen is fully operational and successfully displays maximum apogee, battery voltage, and active satellite locks.

# Updated budget

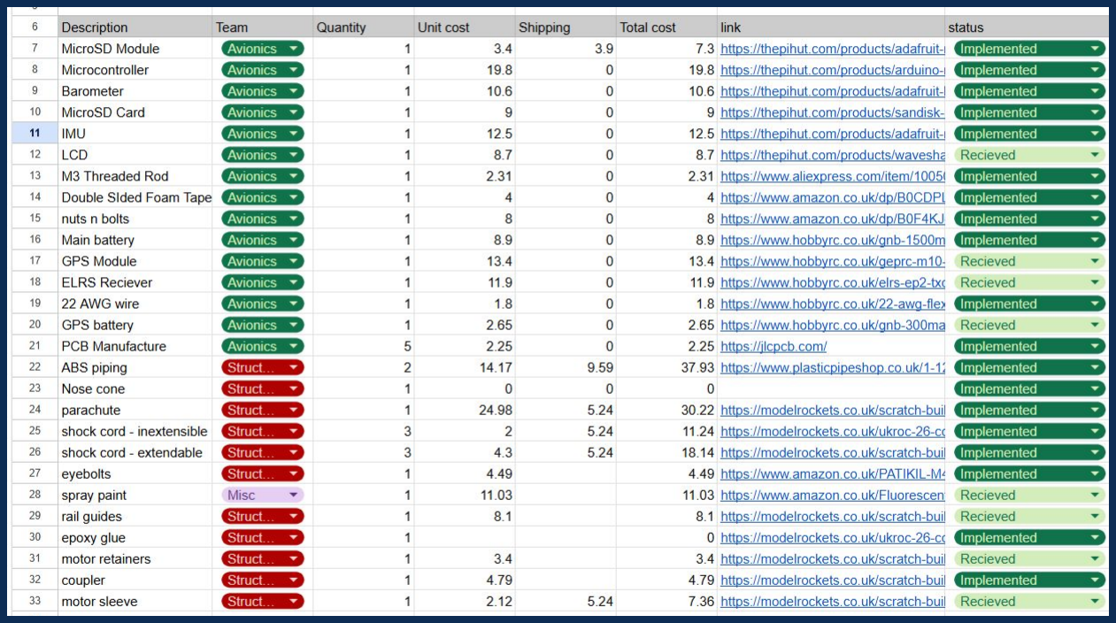
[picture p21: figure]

The total cost of the rocket is now £259.81. All parts have now been bought and received, and the majority of parts have been implemented or are in the
process of being implemented. With testing now complete, this is estimated to be the final cost of the rocket.

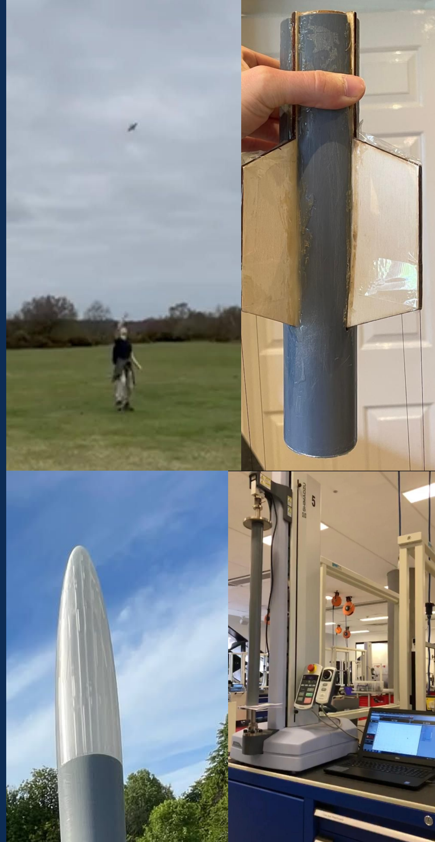
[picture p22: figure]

# Structural strength

- To test the rocket’s structural integrity, a compression test was carried out on the body tube
- At that point, the predicted G-forces on the rocket reached 10.1G -to ensure complete rocket safety the tubing was tested to 2 times the required amount, reaching 200N without any damage or flex, demonstrating the structural strength of the rocket
- Nose cone integrity has also been tested, with a drop test simulating impact speeds of 14m/s, far over the _ the rocket will experience
- Similarly, the fin assembly survivability has been tested, with a drop test demonstrating that the fins are unlikely to snap upon impact with the ground

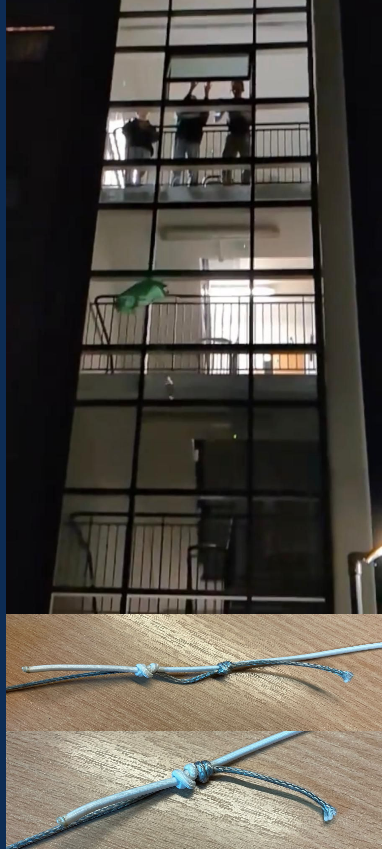
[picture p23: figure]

# Recovery

- The recovery system has been effectively ground tested to demonstrate its effectiveness
- The parachute was drop tested with a weight equal to that of the rocket, and its descent speed was measured to ensure a low impact speed - from this we concluded that the chosen parachute is suitable for the launch
- The eye bolts have been tested by applying a sudden force to the shock cord tied to it - a slipknot was chosen to connect the shock cord due to the characteristic of it tightening when a tensile force is applied to it
- The shock cord itself was tested by fastening one end to a stationary point and pulling the other end to test its comfort under extension. From this we determined that the shock cord is highly unlikely to break during recovery system deployment. A double fisherman’s knot was chosen to connect the different cord segments due to its ability of providing some shock absorption

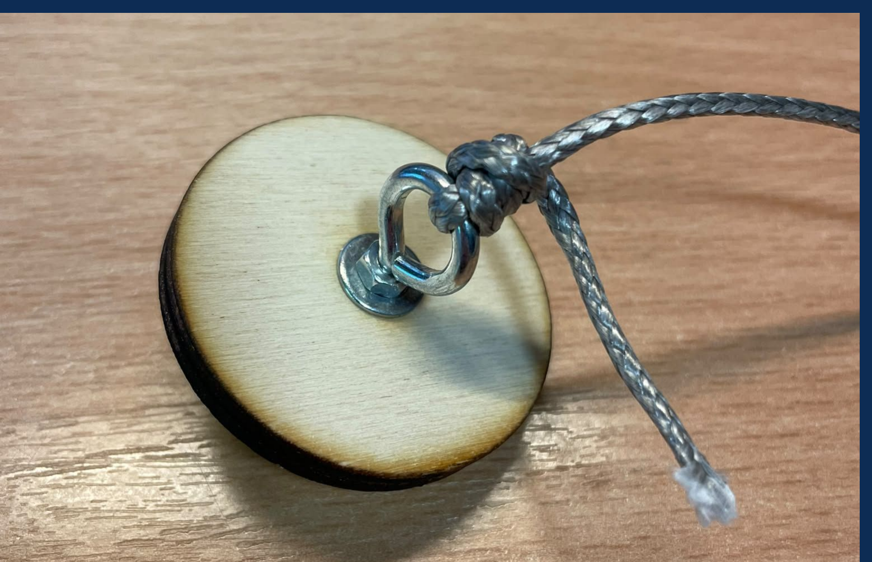
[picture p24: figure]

# OpenRocket

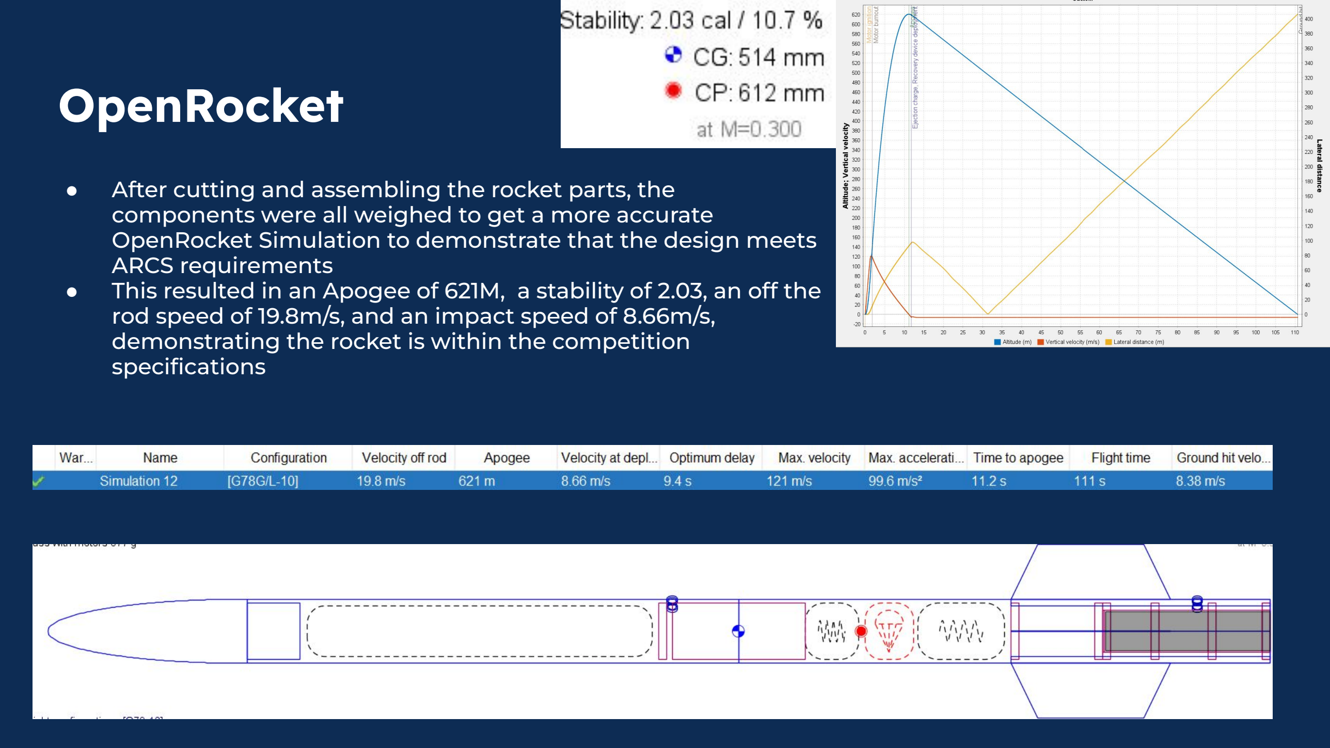
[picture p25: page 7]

- After cutting and assembling the rocket parts, the
components were all weighed to get a more accurate OpenRocket Simulation to demonstrate that the design meets ARCS requirements
- This resulted in an Apogee of 621M, a stability of 2.03, an off the rod speed of 19.8m/s, and an impact speed of 8.66m/s, demonstrating the rocket is within the competition specifications

# CR compliance - Structures

Specifications that have
not been affected since
CDR:
- 1-4-2
- 1-5-1
- 1-5-2
- 1-6-1
- 1-6-2
- 2-1-2
- 2-1-4
- 2-1-5
- 2-1-6
- 2-1-7
- 2-1-9
- 2-1-10
- 2-1-12
- 2-4-1
Specification | Requirement | Compliance
ARCS-CR-1-4-1 | Teams must use safe practices when building their rockets. Construction on rockets should be done using the proper equipment and spaces such as those available in the iForge | During construction the IForge was used for cutting and sanding of the ABS piping, as well as laser cutting and construction of the fin assembly - as these were the most high risk activities it was essential they were carried out in a suitable environment. Spray painting was carried out outside with suitable protection and care. Gluing took place in a well-ventilated room.
ARCS-CR-2-1-1 | Rockets must not be designed to be intentionally unstable or understable. This will be defined within this competition of having a static margin of between 1.6 and 2.2 on the launch rail | Inputting final masses into the open rocket. The stability is 2.03 off rod. which is within the required range.
ARCS-CR-2-1-3 | Rockets shall sag no more than 1% of their total length when suspended from both ends | When suspended from both ends. No visible sag is apparent.
ARCS-CR-2-1-8 | All rockets must be equipped with 6mm rail guides. There must be a minimum of two independent rail guides that align the rocket to the rail at launch, rail guides may not be detached during flight | The rocket has been constructed with 6mm rail guides fastened onto the side of the body tubing.

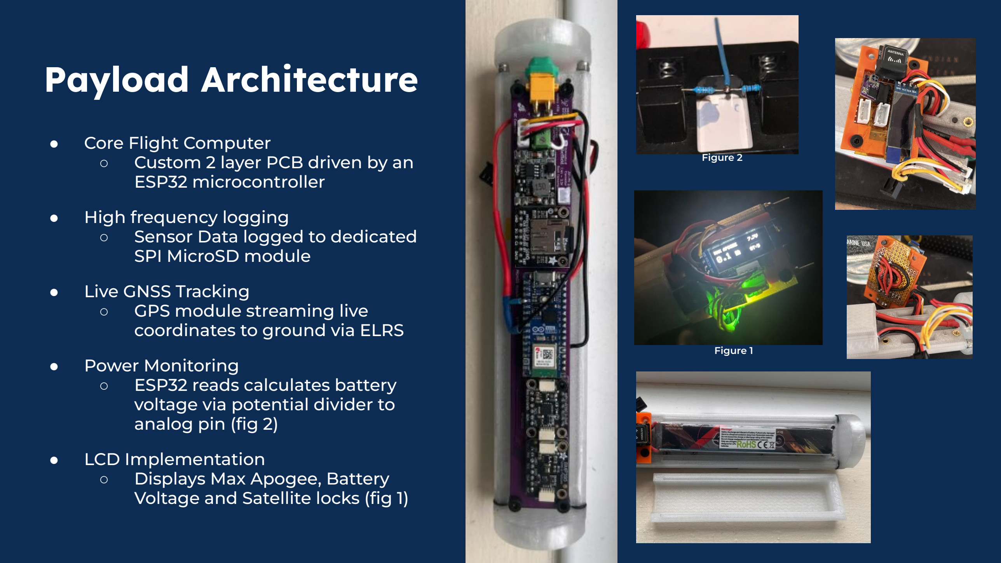
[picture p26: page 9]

Payload Architecture ● | Core Flight Computer ○ | Custom 2 layer PCB driven by an

ESP32 microcontroller
- | High frequency logging ○ | Sensor Data logged to dedicated
| | SPI MicroSD module
- | Live GNSS Tracking ○ | GPS module streaming live
| | coordinates to ground via ELRS
- | Power Monitoring ○ | ESP32 reads calculates battery
| | voltage via potential divider to analog pin (fig 2)
- | LCD Implementation ○ | Displays Max Apogee, Battery
| | Voltage and Satellite locks (fig 1)

Figure 2

Figure 1

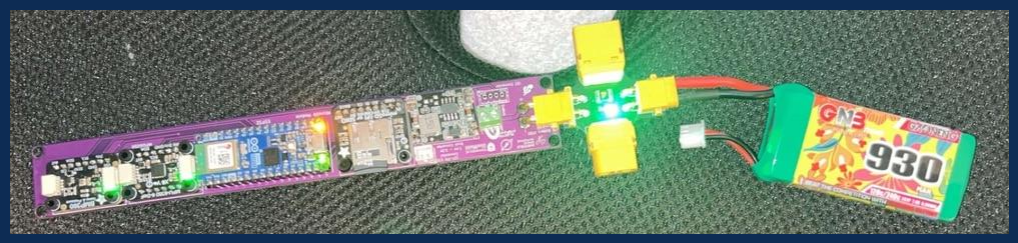
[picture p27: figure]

# Payload Testing

- Smoke-stopper Test
- Passed. No trip. Total isolation between live and ground verified.

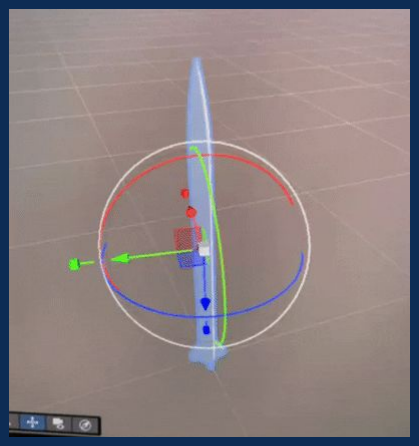
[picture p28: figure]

- Voltage Regulation Test

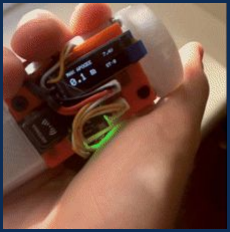
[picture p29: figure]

- Passed. Nominal voltages measured via multimeter. 8.4V Successfully stepped down to 3.3V.
- Battery endurance test
- Passed. Due to lack of camera, upgraded 1500mah LiPo is highly overpowered, resulting in system logging data for multiple hours, well above the required 40 minutes.
- Telemetry and sensor verification
- Passed. Barometer successfully logs increasing altitude when ascending stairs. Inertial measurement unit logs were passed through a 3D vector modeling tool, verifying both gyrometer and accelerometer.
- GPS System Test (NON CRITICAL)
- Partially passed. Successfully locked onto 10+ satellites and accurately found GPS coordinates, however, link between receiver and ground station yet to be finalised.


# Payload Integration

The forward bulkhead is
permanently epoxied directly to the shoulder of the nose cone, creating a single rigid assembly.

The entire assembly is locked into the upper airframe using M3 stainless steel pan-head screws driven radially through the airframe. This completely replaces permanent epoxy joints allowing access, whilst providing high shear resistance against ejection forces and ground impact.

Tensile loads from parachute deployment and ground impact are carried by the dual M3 threaded stainless
steel rods running through the entire sled. Secured
with Nyloc nuts, ensuring high vibrations doesn't
shake them loose. | The lower bulkhead has a
| hole to route a cable to
| power the committee
| payload (red).

By removing the radial
screws, the entire avionics assembly slides out from the forward end of the rocket by pulling the nose cone gently. This allows for rapid
pre-flight setup and data
extraction without touching the recovery end of the
rocket.

The bulkheads have been
changed from plywood
to high infill, high wall
loop PETG, greatly
reducing the chances of
the radial screws
shearing compared to
plywood.

# Data display

## Post recovery. The SD card will be removed from the rocket and the

data will be extracted and displayed using matlab.


Graphs made from a mock set of data from testing.

# Avionics CR Compliance

Specification | Requirement | Compliance
ARCS-CR-2-2-1 | All teams must ensure the place is well ventilated before soldering any component. Additionally, all teams must ensure that all solder used is lead-free. | All soldering performed in ventilated spaces using lead-free solder.
ARCS-CR-2-2-2 | Before connecting a battery to your components, verify that no short circuits are present and everything is routed correctly. We suggest using a smoke-stopper when first testing avionics. Ensure that the battery is not routed to the USB port of your device. | The battery is never routed to the USB port; electrical continuity tests are in place. A smoke stopper will be used.
ARCS-CR-2-2-3 | Batteries above 7.4V are not allowed. | We will use a 2S 7.4V LiPo battery.
ARCS-CR-2-2-4 | It is recommended to use multi-core wires for signal connections. Connectors such as JST and XT are recommended as well. | Use of multi-core wiring for all flexible connections to prevent fatigue. Using XT30 connector for our battery.
ARCS-CR-2-2-5 | All teams must mechanically mount (i.e. with screws & bolts) their PCB; hot glue or epoxy can’t be used to stick your avionics to the avionics bay. PCB mounts must be designed to resist the shock forces experienced by the rocket during its flight. | Our PCB mounts to the 3D printed sled with 11 screws into heat set threaded inserts. Our avionics bay uses rubber o rings between bulkhead and sled to reduce the effects of vibration. M3 stainless steel rods run axially, through the avionics bay, fronting the tensile loads, and the bay is screwed in radially, providing strong shearing strength.


# Decoration

- The colours chosen to paint the rocket have been altered in favour of maximising visibility to aid in rocket recovery. For this reason the body tube was sprayed with a colour gradient of red, neon pink and neon orange, with the nose cone and fins being sprayed with blue
- The team name and logo will be painted along the body in blue to match the nose cone and fins.
- To ensure better adhesion to surfaces, a layer of primer was applied - this also increased the brightness of the paint sprayed on top of it, further helping with recovery

# Last steps of assembly

## - Drill holes for barometer(this will done on 02/06)


## - Paint lettering using stencil - Screw in rail guides(will be done after painting the lettering)

# TEAM PHOTOS


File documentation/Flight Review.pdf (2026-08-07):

### Flight Summary - ARCS Team 1 - Electric Dysfunction

The rocket demonstrated an aggressive launch profile that was ultimately compromised by a mechanical recovery failure. Off the pad, the vehicle exhibited notable angular deviation, characterized by sudden pitch and yaw oscillations captured in the raw gyroscope data and visually. This behavior is likely due to an overstable configuration (simulated at 2.05 calibers). After clearing the launch rail, the rocket instantly weathercocked into the crosswind, corrected its path, but overcorrected resulting in some oscillations before locking into a stable upwards trajectory. Our measured apogee was 411m, which cannot be confirmed with the Committee Research Payload as the data was lost when the power was disconnected. This less than expected apogee can likely be put down to the initial oscillations increasing drag and cosine losses.

The primary failure mode occurred at apogee, where the airframe failed to decouple. The late addition of recovery wadding and a tightly packed Nomex protector sheet restricted the linear volume inside the airframe. Under the pressure of the ejection charge, this tightly packed bundle likely compressed and expanded radially, jamming itself against the inner walls of the recovery bay. Because the gas could not bypass or push through this fabric plug to decouple, the ejection gases forced its way backward and blew out through the spent motor casing instead of separating the airframe. Lacking parachute deployment, the vehicle entered a stable ballistic descent, maintaining structural integrity until it impacted the ground at 80 m/s.

After searching through the tall grass and wild field for around 2 hours, we eventually recovered the rocket. The PETG nose cone was buried in the ground and had sheared off, whilst the forces travelled through the stainless steel rods in the AV bay, snapping the rocket in half, subsequently obliterating the fin assembly. After prying the AV bay out, we were pleased to discover that the AV bay had drastically overperformed structurally and was powered on and logging. Despite the 180 mph impact, the 3D printed PETG sled, mounting infrastructure and solder joints remained intact and flight logging data uncorrupted. This was a huge success in terms of the useful data we acquired and as such the rocket was not a total failure.

### MATLAB Data Plots


80 m/s impact


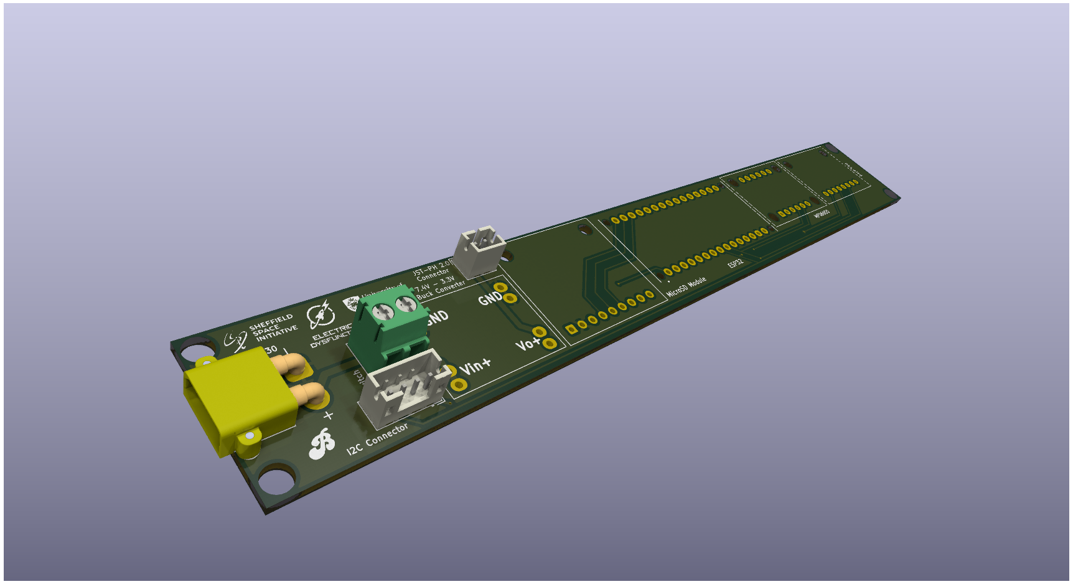
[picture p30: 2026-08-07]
hardware/PCB Render.png

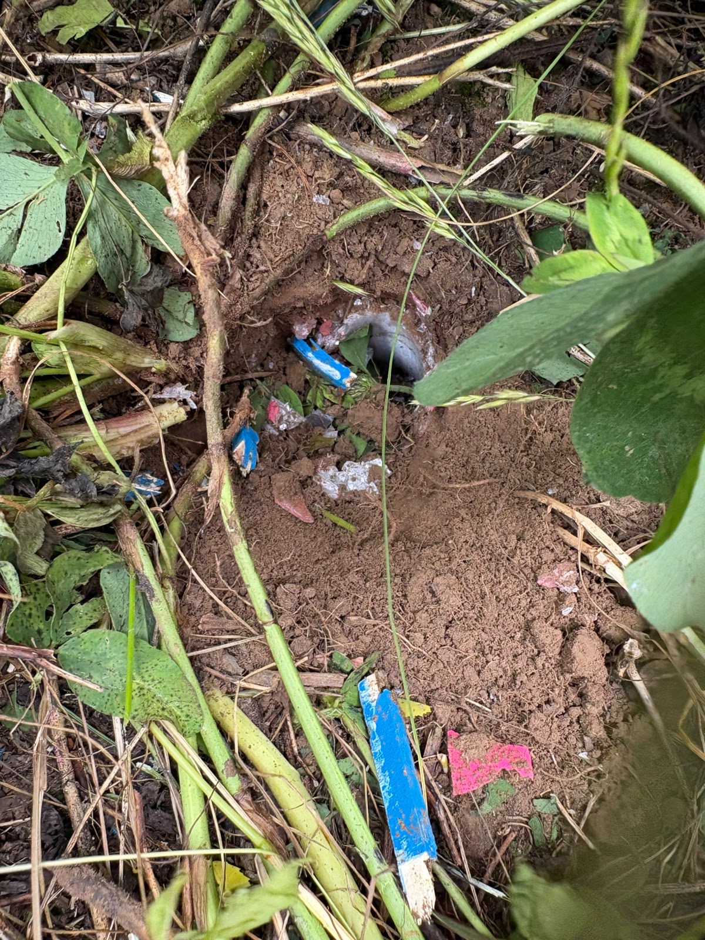
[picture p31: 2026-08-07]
media/2dca02a0-d403-4357-a7e4-8b94c686a729.JPG

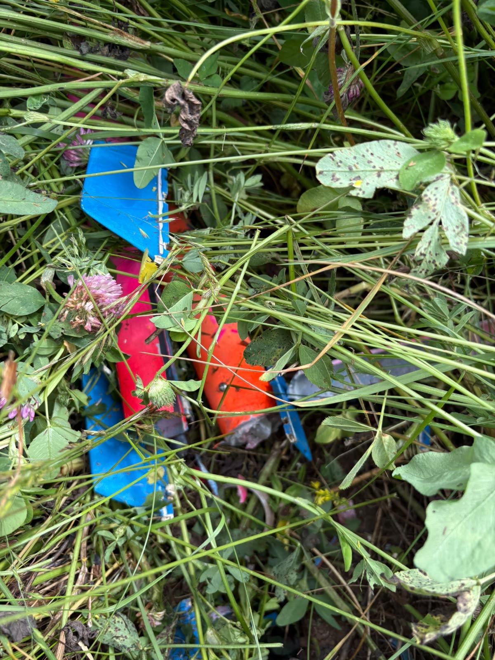
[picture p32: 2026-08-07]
media/d7e7c3e2-7049-4fd6-9817-dbeb2e40438d.JPG

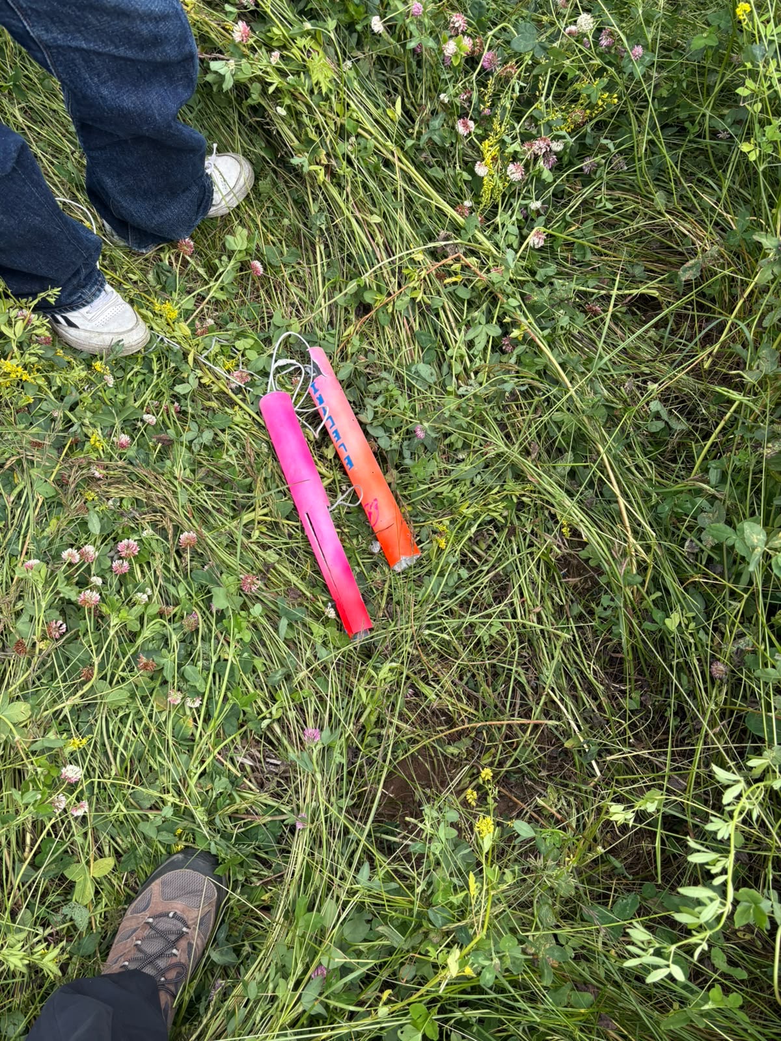
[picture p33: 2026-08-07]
media/e03ca3a9-e661-4cca-b87a-2b84523ee567.JPG

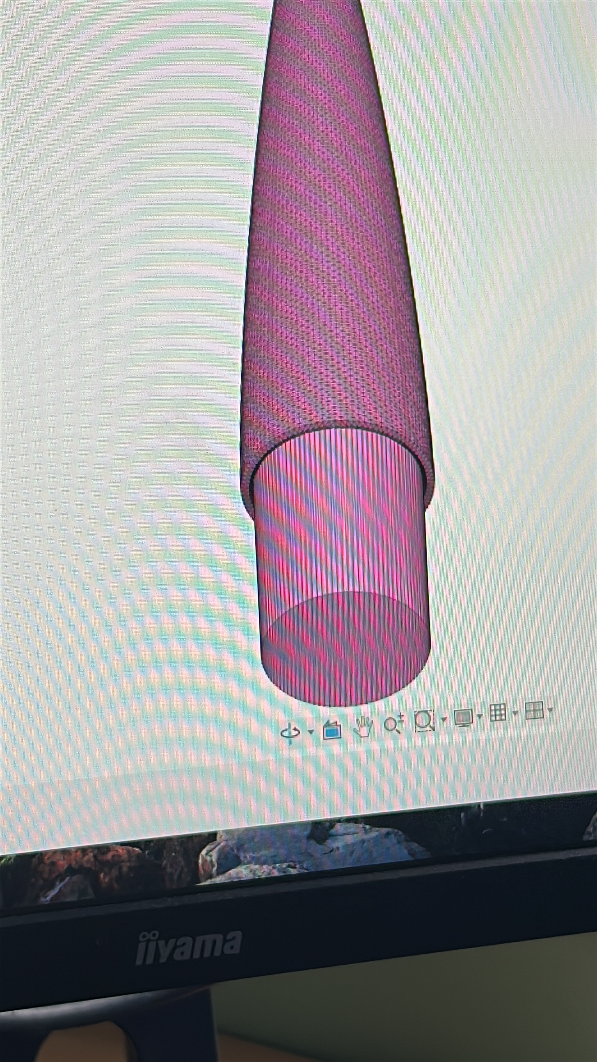
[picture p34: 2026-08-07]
media/156E5A83-E5EA-4D38-9C8F-6319BE2258A0.JPG

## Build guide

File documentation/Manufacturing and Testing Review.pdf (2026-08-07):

# Manufacturing and Testing Review

## Electric Dysfunction Arcs Team 1


# Contents

# 1 - Team Structure

Post the CDR, the structure of the team has stayed the same, however as manufacturing and testing has begun there are new allocated assignments for each member of the team. Each teammate has been assigned a specific task for either testing/manufacturing as listed below.

# 2 - Timeline

## 2.1 - Structures

Name | Role | Lead | Assignment
Sam Orlin | Avionics | Avionics lead | Payload Design and Manufacture
Finn Woolley | Avionics | | Data Analysis & Nose Cone R&D
Alistair Wye | Avionics | | Data Manipulation & Filtering
Charlie Sims | Avionics | | Payload Bay Design
Olivia Gransden | Structures | Team lead | Organisation/testing
Lara Burke | Structures | Vice team lead | Organisation/testing
Louis Goodwin | Structures | Structures lead | Strength testing
Lewis Cairns | Structures | | Nose cone design/testing
Sophie Shandley | Structures | | Testing/manufacture
Dan Hubbard | Structures | Vice structures lead | Fin R&D/testing and OpenRocket designs
Robert Seddon | Structures | | Testing/manufacture
Freddie Kendall | Structures | | Strength testing
Tyler Cain | Structures | | Testing/manufacture
James Barnet | Structures | | Nose cone testing

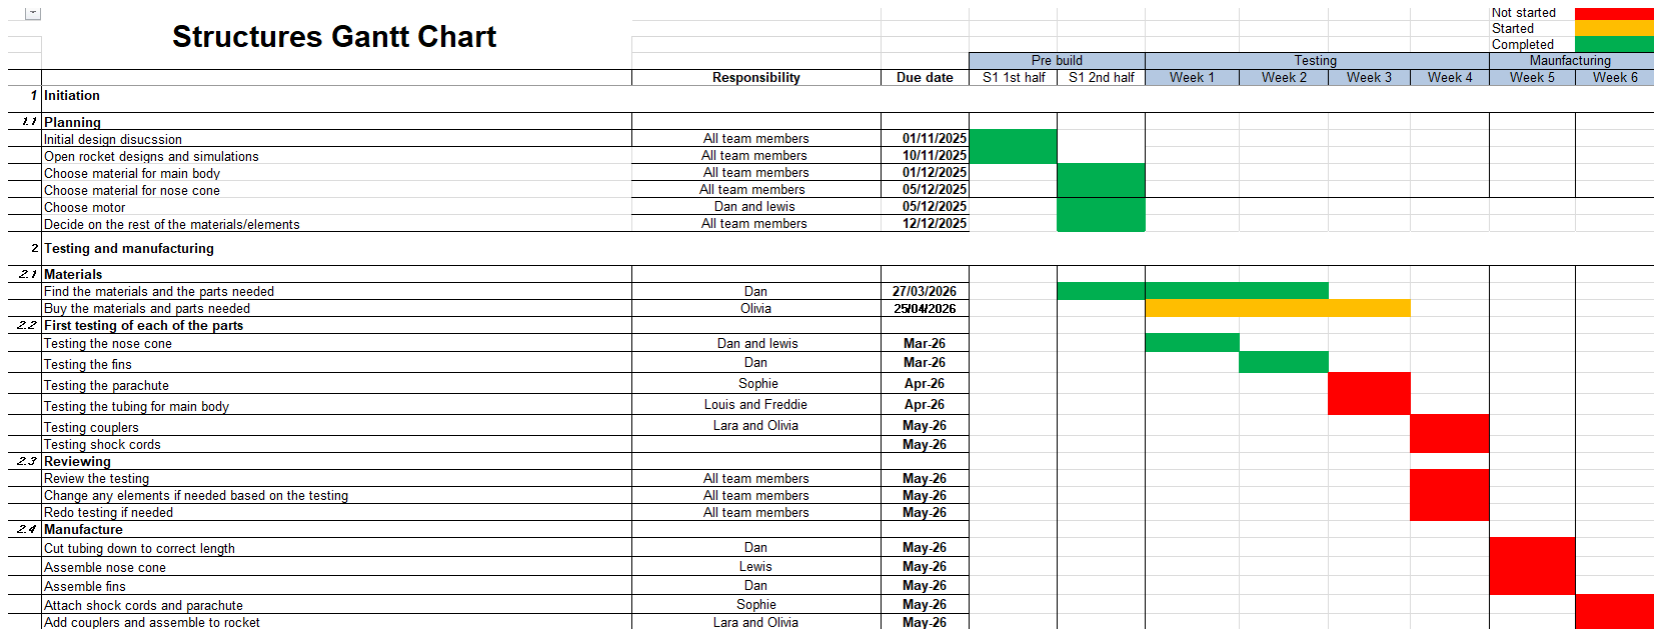
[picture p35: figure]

There were many changes to the rocket design once the team was provided with feedback from the CDR, resulting in a small setback with the testing and manufacturing stages, causing the timeline to shift most of the testing to April rather than March as previously intended. The focus now is making sure each element has been tested and changed, if needed, ready for the final assembly.

## 2.2 - Avionics

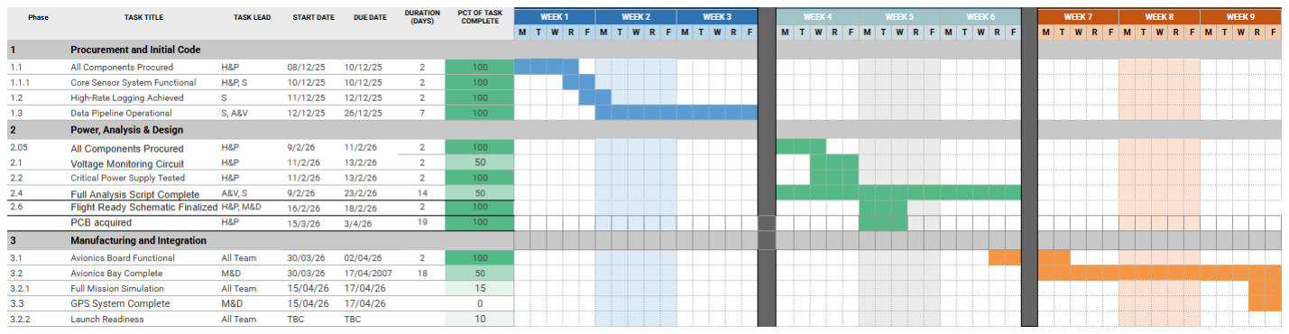
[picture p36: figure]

With the core structural components manufactured and the Avionics PCB successfully verified, the focus shifts toward final system integration and software refinement. The upcoming phase will be broken down into the following key objectives:
- Hardware Integration: Finalising the integration of the PETG avionics sled into the main airframe, as well as securely mounting and wiring the u-blox M10 GPS telemetry system.
- Power Monitoring: Establishing a voltage divider circuit. This will step down the 8.4V main flight battery to a safe logic level, allowing the microcontroller to monitor battery health and log discharge curves during flight.
- Software & Data Pipeline: Transitioning into the software testing stage. This phase will focus heavily on implementing sensor filtering algorithms to smooth raw barometric and IMU data for accurate apogee detection and optimising the I2C/SPI data pipeline to ensure high-frequency logging to the MicroSD card.

# 3 - Budget

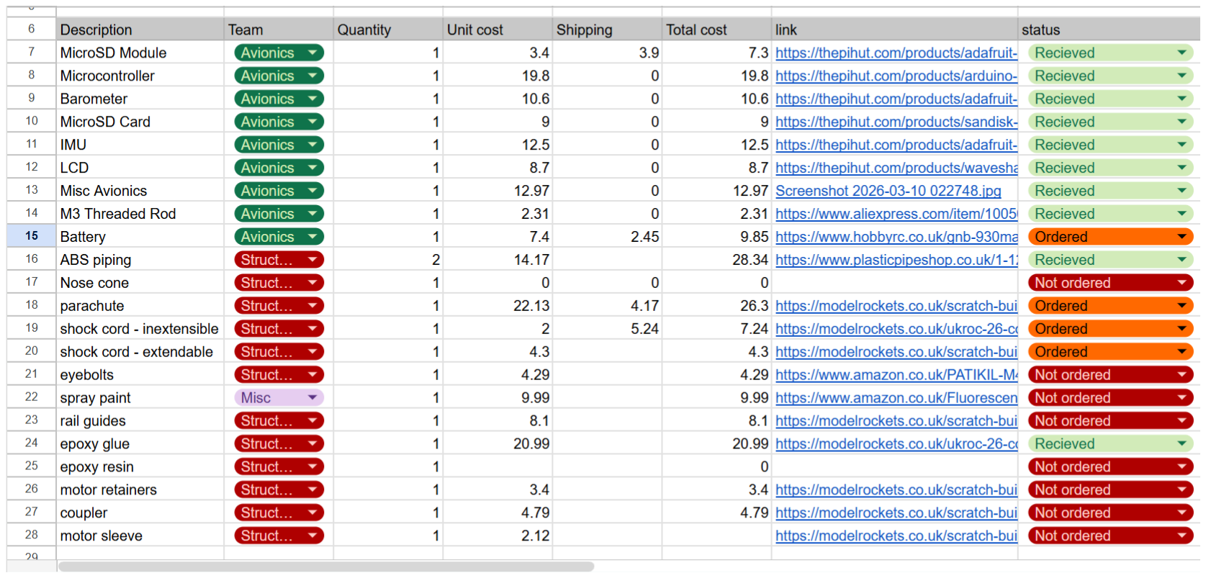
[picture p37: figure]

The spreadsheet above displays the current costing sheet for all components necessary at this point in the competition. The approximate total cost is currently £206, slightly exceeding the reimbursement of £200 from ARCS, however members of the team have contributed to make up for any current and potential future additional expenses that may arise during manufacturing and testing. Some aspects of the manufacturing do not have any cost due to the use of university facilities such as the iForge, where student credit and free facilities/materials will be used where possible. Now that research and costing for parts has been finalised, the components that are linked in the costing sheet are in the process of being ordered and tested by the team.

# 4 - Updated Open rocket Simulations

As before, one goal for the team was to reach a maximum apogee of 610m while attempting to keep the flight of the rocket as stable as possible as well as safe to fly; the rocket must also hit the ground at a speed which means it will be recoverable. The simulation took place with a wind speed of 10 knots to give a realistic understanding of the rocket's performance.

## 4.1 - Motor change:

Due to an error on the open rocket which added an additional 2 second delay to the motor, the G87-7 was incorrectly chosen during the design process. This mistake was discovered in the CDR causing a new motor to be required. The G78-7 was swapped for a G78-10 due to its closeness to the optimum delay of 9.43s. The dimensions of each motor are the same causing no changes to the fin assembly to be made.

## 4.2 - Velocity off rod:

The design has a velocity off rod of 14m/s, slightly slower than previously, but still good enough to ensure the rocket is aerodynamically stable during early parts of the flight including take-off. The fins will allow the rocket to correct itself here.

## 4.3 - Stability

This design is suitable as it has a stability of 2.16 calibers, meaning the center of pressure is just over two body diameters behind the center of gravity, providing a strong but not excessive restoring force for stable flight. If stability was too much lower than this, then the rocket wouldn’t have a smooth take-off as well as ascent. Especially if there is wind on the day, this would mean the rocket is prone to being blown off course. If the rocket was too stable, it would make it prone to weathercocking so stable, steady flight would once again not be achieved.

## 4.4 - Ground hit velocity

The estimated ground hit velocity is now slightly higher at 8.07m/s. After testing was carried out on the nose cone, it was established that the nose cone would survive an impact with grass at this velocity and so no further modifications to help this are needed.

Once the descent rate of the rocket is measured with the parachute, it will be compared to the simulated descent rate on OpenRocket. A higher descent rate would increase the likelihood of breaking on landing, while a much lower descent rate would reduce landing accuracy. The rate should ideally fall around 7m/s as it provides a balance between safe touchdown and minimal drift distance.

## 4.5 - Apogee

An initial assumption was that OpenRocket overestimated the overall apogee by approximately 10%. This led to the initial design having a higher apogee of 674m to allow for this. However it is now led to believe OpenRocket is more accurate so there was too much overcompensation, meaning there were changes in the design to allow the new apogee of 635m to be reached. This will mean the rocket will reach the desired height of 610m, whilst still compensating for any
differences.

The updated model also reaches an estimated lateral

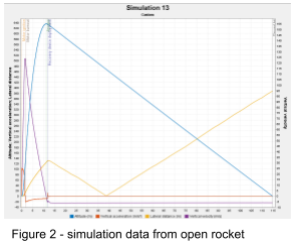
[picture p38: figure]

distance of approximately 390m, which is better than previous designs as a result of improved stability on the rocket. This will help when trying to recover the rocket.

# 5 - Manufacture

Manufacture started shortly after the CDR was submitted. The main focus was to manufacture the fin assembly as that is the most complicated and intricate structural part of the rocket. In addition, a large focus was put into the avionics bay
manufacture so its connection to the rest of the rocket can be tested.

During manufacture several issues were found with
the design causing new designs to be made which
differ from the CDR. These include the nose cone, fin

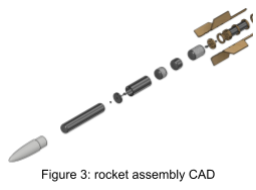
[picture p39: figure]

assembly and bulkheads. All changes will be explained and justified in their corresponding sections.

## 5.1 - Fin assembly

Post CDR, the fin assembly was laser cut and glued. The first iteration used 3mm plywood for both the centering rings and fins. Through inspection, it was decided that the centering rings needed to be thicker so they would be more suitable to withstand the forces of the rocket motor. On the second iteration the centring rings were made of 6mm plywood and the fins 3mm plywood (see figure 4). Fin assembly V1 was fit tested with the G78 motor, during this it was discovered that a motor sleeve was necessary to ensure a good fit with
the motor. This was then incorporated into the
CAD design (see Figure 6).

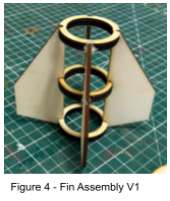
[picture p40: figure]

In addition to this it was noted that the fin size was quite small in proportion to the length of the rocket. This led to the design of the fin assembly V2 (see figure 5). Design V2 has the fins moved up the body of the rocket. Moving the fins up the body reduces the effect on the rocket stability requiring them to become larger to have the same effect. This makes the V2 fins much larger than the original design (approximately double the area). Note that in figure 5 the assembly is positioned upside down. During the assembly of V2 it was found to be very difficult to align all the fins to be at 90° from each other. Due to

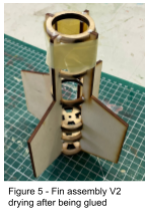
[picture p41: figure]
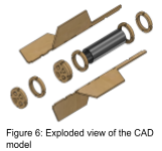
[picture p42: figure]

this a Jig was designed to keep the fins straight during gluing. This will be used during the assembly of fins V3, and will be 3D printed out of PLA to ensure it has the correct dimensions.

The fin assembly will be attached to the
tubing via four 195mm long slits cut into each side of the tubing. The current plan is to use a coping saw to do this - however alternate methods such as using a dremel or a bandsaw are being considered for their ability
to cut straighter lines with more ease . The
glued fin assembly can then slide into the

tube and be attached using epoxy glue. To assure the cuts are in the correct location a Jig has been designed to assist in the cutting - this will be 3D printed out of PLA to minimise human error and ensure the slits are in the correct places.

## 5.2 - Body tube

Two 1m long ABS tubes with inner diameter 42.7mm and wall thickness 2.8mm were purchased for manufacture and testing. One tube was cut into 2 sections of 730mm and 230mm via a tenon saw. The 730mm length will be used for strength testing (see section 6.2). The 230mm length was used to manufacture a mock fin assembly for strength testing

(see section 6.5). Once the strength testing has taken place the 730mm length will be cut into 400mm and 330mm lengths to imitate the dimensions of the rocket. These sections will be fitted with a coupler and be used for the sag test (see section 6.4). The second tube has been left aside to be used for the manufacture of the rocket's components in case any of the tests damage the body tubing.

## 5.3 - Nose cone

Nose cone V1 was 3D printed in the iForge using PLA. At first the nose cone was printed as one continuous piece to improve its overall strength. However, due to its length it just exceeded the limit for what could be printed in the iForge. This meant it had to be redesigned yet again and printed in 2 sections which was only just allowed to be printed, being close to the maximum time allowed. These 2 halves were then attached together via epoxy glue and left to set. The nose cone was then sanded and used for testing (see section 6.1) to remove any excess epoxy and get a better look and
representation of the real thing. It was also done to
practice the assembly process.

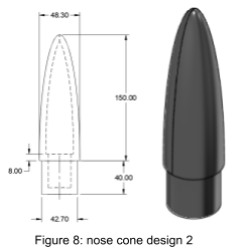
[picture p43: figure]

Due to the new fin V2 design, the nose cone was shrunk to reduce its mass. This created Nose cone V2 (see figure 8). Which has reduced the amount of print that will be used and also the length of the nose cone to decrease the weight.

The method to attach the nose cone has been changed. Instead of using epoxy glue to hold the nose cone in place, stainless steel pan-head screws will be used. This is to allow the nosecone to be removed so that the avionics bay can be accessed. However, if screws are used the extraction of the avionics bay becomes much simpler and any complications surrounding getting it out are gone. Different screws than what would be used for the bulkheads would be used as this is a plastic compared to wood.

## 5.4 - Bulk heads

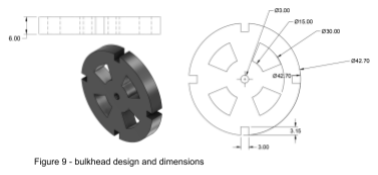
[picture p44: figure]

The bulkhead design has also been altered post CDR. After further research into how the rear assembly of a model rocket is designed [1], an additional bulkhead was added behind the original 2 to provide a buffer against the motor itself. Furthermore, the rear 2 bulkheads were redesigned to allow airflow from the charge to pass through and deploy the recovery system effectively. Gaps were placed in the design to allow air to pass through the bulkhead after being redirected from their original path - this also meant that the rear bulkheads acted as baffles, protecting the shock cord and parachute from the harmful ejection gases released from the charge.

Another change from the CDR was the decision to use 6mm Plywood rather than 3mm - with this increase in thickness the strength of the bulkhead would be more likely to withstand the hot gas ejection of the motor as well as the forces from the recovery system deployment. Additionally, the increased thickness provides a greater surface area for gluing the bulkheads onto the body tube, minimising the risk of a rapid unplanned disassembly upon parachute deployment.

## 5.5 - Custom PCB Manufacture

The flight computer is a custom-routed PCB developed over many months of an iterative design process using KiCad. Since the CDR, the PCB design has changed significantly. The previous design did not consider the height added due to the breakout boards and power connectors. Due to the small inner diameter of the rocket, the design was required to be much thinner and more compact. The pull up resistors and decoupling capacitors were removed once it was discovered that the breakout boards already included them internally. Tracing was improved, including parallel connections between sensors, and all components were moved closer together. A custom I2C connector (JST-PH 4 pin) was added to connect a screen for the apogee display. The buzzer system was also removed due to concerns about ineffectiveness and legality raised in the CDR feedback, and replaced with a GPS module and ELRS receiver to transmit GPS coordinates to an ELRS ground station. The battery capacity was increased from 800mah to 1500mah due to concerns about high current draw.

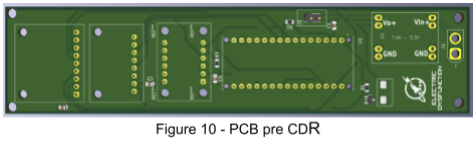
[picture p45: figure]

Upon receiving the fabricated boards from the manufacturer, a rigorous unpowered visual and multimeter inspection was conducted. Isolation between ground and live was confirmed for both the 8.4V and 3.3V lines. During this phase, a mistake was identified. The screw terminals for the external power switch were bridged due to a trace routing error in the KiCad file. This meant that the switch was always closed, regardless of the screw terminal state.

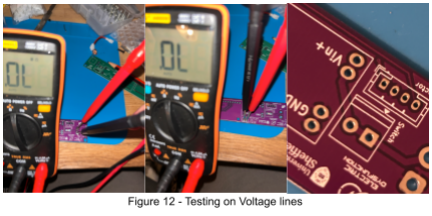
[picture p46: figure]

Instead of waiting weeks for a manufacturing replacement, the board was manually reworked using a precision blade to carefully remove the copper trace bridging the pads. Subsequent continuity tests confirmed the bridge was successfully cleared and the circuit was open as intended.

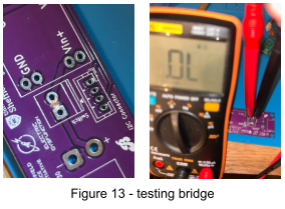
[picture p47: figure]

Following the rework and initial continuity tests, all through hole components were soldered onto the board by hand using lead free solder and high quality flux before beginning the Avionics Testing (see 7.3). Rubber dampers are added onto the sensors and microSD module to prevent vibrations causing noise or affecting the data logging. M2 x 8mm screws held in place with acrylic hex nuts mount the modules to the board.

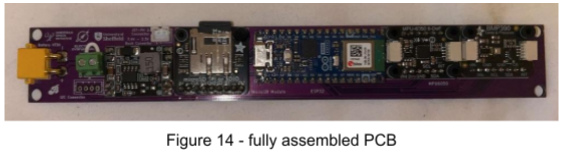
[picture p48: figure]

## 5.6 - Avionics Bay

The avionics suite is housed within a 3D-printed sled, designed for accessibility and structural rigidity. The assembly is centred around two stainless steel threaded M3 rods that provide the primary load path for the internal components.
The threaded rods are secured using Nyloc nuts and external tooth lock washers. This combination was selected specifically to resist the high frequency vibrations experienced during the motor burn and the mechanical shock of parachute deployment, ensuring

the stack does not loosen in flight.

The internal assembly is suspended between two bulkheads each held in place via external stainless steel pan-head screws. To access the avionics bay, the nose cone is first removed by unscrewing the side entry screws holding it in place. Next the avionics bulkheads are unscrewed, allowing the entire AV bay to slide out.

Version 1: Initial Proof of Concept
The initial sled design served as a proof of concept to verify the board dimensions with the airframe and to visualise the space available. However, testing revealed that the clearance holes for the structural threaded rods were too small, preventing the M3 threaded rods from sliding along the sled. Furthermore, the holes ran too close to the edge of the bay, causing a failed print. This design did not include a dedicated, secure mounting location for the flight battery as the battery dimensions were not known at the time.

Version 2: Refined Tolerances, Heat-Set Inserts and Battery Accommodations
V2 significantly improved upon the mechanical stability of the sled. The holes for the threaded rods were adjusted, using a 3.7mm diameter hole instead of the previous 3mm. This, and changing the position of these holes so that they weren't so close to the edge, eliminated the printing failures of V1. Securing the PCB directly into the plastic print risked thread stripping in the high vibration environments, so a soldering iron was used to embed brass, heat-set inserts into the sled allowing the PCB to be screwed in and out without degrading the plastic. A dedicated battery cavity was also drafted into this model which needs major improvements due to space issues and cable management ineffectiveness.

Version 3:

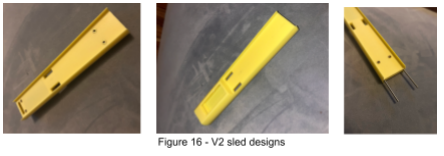
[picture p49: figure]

Version 3 provided improvements on V2, particularly improving on the battery cavity for the new 1500mah main battery, as well as creating a slot for a secondary battery to power the GPS system. Above this slot, there is an area to mount a protoboard, which will be for the GPS system and for a small screen to mount and read out apogee, post flight. The threaded rod holes were adjusted once again to 3.5mm to reduce lateral play inside the airframe, which worked perfectly.

Version 3 addressed all major concerns, finalising this prototyping phase. The next bay will be the final design and will be almost identical to V3, but with cable management holes, external anchor points for battery securing and will be printed from PETG, for its thermal stability.

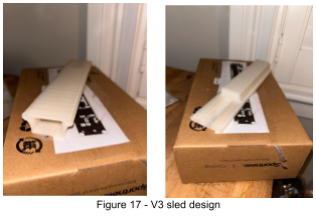
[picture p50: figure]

## 5.7 - Decoration

The rocket's colour scheme will be a blue body, with a red nose cone and fins. The team name will be written on the side in red along with the team logo. This colour scheme is due to 2 major factors:
- The bright colour will aid with spotting the rocket for recovery purposes.
- The composition of the two contrasting colours makes it visually appealing.
The design will be added using spray paint as well as stencil to add the lettering.

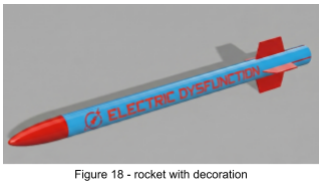
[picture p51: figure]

# 6 - Structural Testing

## 6.1 - Nose cone drop testing

During the launch, the Rocket is simulated to have an impact speed ≃ 8m/s. To assure the nose cone will be strong enough to sustain this impact, it was decided to test the nose cone at a higher speed ≃ 14m/s. This was achieved by dropping from an approximate height of 10m. Using:

V

2 = U

2
+ 2aS

Subbing in the height (10m), acceleration due to gravity (9.81 m/s ) and initial speed (0m/s). The impact speed is shown to be

2
14-15m/s. The nose cone was to be dropped onto grass to
simulate the conditions it will occur under the real launch,
however the first attempt landed onto a concrete panel causing a

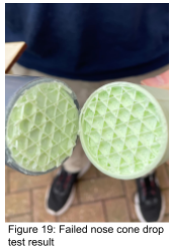
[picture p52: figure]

structural failure (see Figure 19). After repairing, the nose cone was dropped onto grass with no damage. With this test it is shown that the nose cone will be able to sustain the impact speed without any damage.

## 6.2 - Compression tests

During the launch, the rocket will undergo a compressive stress due to the acceleration caused by the motor. To ensure the tubing chosen is strong enough to withstand the stress, compressive tests will be performed in the structures lab.

Tubing will be loaded with weights to create a stress which exceeds the maximum compressive stress that the tubing will be submitted to. This will ensure that the tubing won’t fail during the flight. To load the tubing, an option is to tie rope to a strong bit of metal which will be placed on the top end of the tube. The rope will be inserted through the centre of the piping. The tube itself would be suspended vertically. Weights will then be attached to the bottom of the rope via a hook until the maximum expected compression force of around 100N is exceeded.

## 6.3 - Sag test

According to ARCS-CR-2-1-3, the rocket may not sag more than 1% of its total length when suspended from each end. With a length of 88cm, this gives a tolerance of 8.8mm. This will be tested once the lengths of body tubing have been cut - if the current design does not fulfil this requirement, the length of the inner coupler will be increased to provide more resistance to sagging.

## 6.4 - Fin test

According to ARCS-CR 2-1-6, the fins must be able to sustain a force equal to :

F=2g
maxMfins

Where: g
max =

amax
9.81
Subbing in a | (107 | ) and | (0.043Kg), the max | m/s
2 | Mfins

required force is 0.94N which is equivalent to a 95.6g mass. To assure the fins are of suitable strength the fins should be tested with a 100g mass. Combining this with the requirement from ARCS-CR-2-1, a mass of 921g was applied equally across the fins to test if they could hold the
weight of the rocket without 10 degrees of sag.
From the test shown in Figure 20, it was

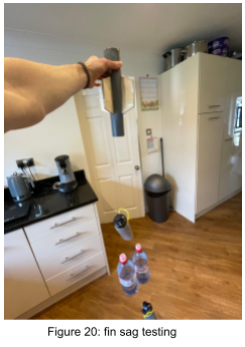
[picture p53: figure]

determined that there was negligible deflection of the fins, successfully demonstrating that the rocket fulfils ARCS-CR-2-1.

As well as the in weight test, an impact test was carried out
to determine whether the fins would survive collision with
the floor upon descent. Using the testing rig shown in Figure 21 and dropping it from a height of 10m (simulating an impact speed of 14m/s), it was found that the fin assembly is extremely likely to survive ground impact due to the fins not sustaining any damage from the test.

# 7 - Functional testing

## 7.1 - Parachute, shock cord and eye bolts

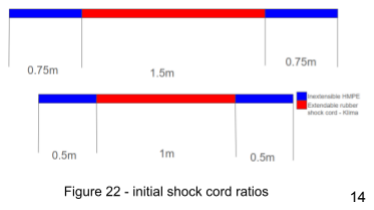
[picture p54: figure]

The initial shock cord design
comprises a 50/50 split between
the HMPE and rubber shock cord
(see component links). Using a black powder calculation
website[3], the shock cord and recovery system would need to withstand 591N. To test this, the shock cord and eye bolts will be put under a force equal to this to see if it can withstand the separation forces. From this, the ratios between HMPE and rubber will be altered to minimise the force applied to the bulkheads whilst also avoiding the shock cord snapping.

For the parachute, a drop test with a simulated weight of the rocket will be carried out from a height of 6 floors (20m). To measure the efficacy of the test, a slow motion camera will be used at the bottom to measure the rate of descent against a known distance - this can then be used to test whether the parachute will allow the rocket to descend at a suitable speed.

## 7.2 - Separation

Once the inner coupler has been attached to the tubing, separation tests can occur. The fit between the upper and lower sections will be assessed to make sure it is correct. A too tight fit can be adjusted via sanding and a too loose fit can be fixed by adding tape to increase the friction between the coupler and tubing. The rocket should be able to separate via a small pull but not due to gravity alone. The couplers themselves must comply with the statement of requirement ARCS-CR-2-1-7: “All tube couplers must be a minimum of 2 diameters long, with each side of the connector extending a minimum of 1 diameter into its receiving body tube.”

The couplers should be tested together by connecting the rocket by the couplers, then adding increasing weights to one side and recording any sag, rotation or movement. Additionally, dropping small weights a small distance, this is to test how the couplers handle sudden loads. Then this process will be repeated for the other side. This will prove that the coupler can withstand the force when being launched to prevent separation.

## 7.3 - Avionics Testing

Test 1: Smokestopper Test
- Objective: Safely supply battery power without risking catastrophic short circuit or LiPo thermal runaway.
- Method: Battery is connected to the PCB in series via a smokestopper.
- Result: Passed. The smokestopper did not trip, indicating no high-current shorts were present on the board.

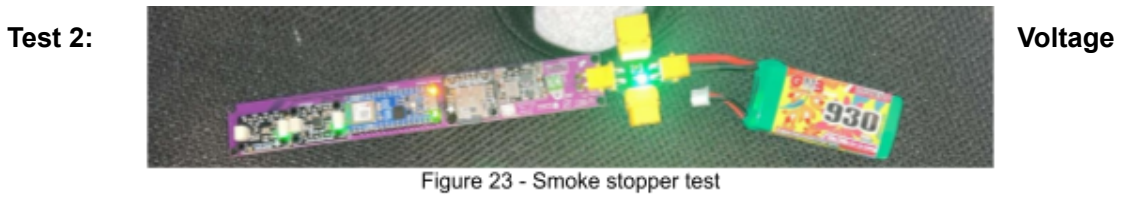
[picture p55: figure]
Test 2:; Voltage

Regulation Verification
- Objective: Ensure 8.4V (full battery) is supplied to the PCB and safely stepped down to 3.3V for the logic components and committee payload.
- Method: With the battery connected, a multimeter is used to measure the voltages of the battery connector, buck converter, and committee payload connector.

- Result: Passed. The system took the nominal 8.4V battery input and stepped it down to a stable 3.3V.

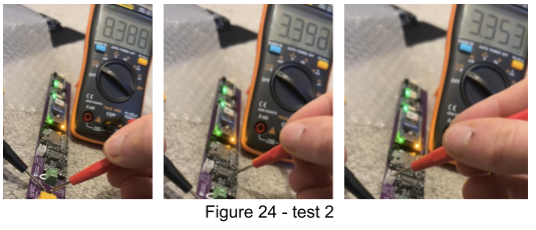
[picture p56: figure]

Test 3: Functional Verification
- Objective: Verify the ESP32 and all I2C/SPI sensors survived the soldering process and operate correctly.
- Method: The board is powered on and connected to the serial monitor to observe live telemetry.
- Result. Passed. All sensors initialised and logged data to serial monitor at high rates.

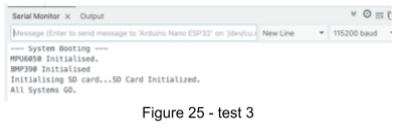
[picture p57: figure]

### 7.3.1 Tests to be Performed:

Test 4: Vibration and Shock Tolerance
- Objective: Verify that the high-frequency vibrations of the motor burn and the physical shock of parachute deployment will not cause brownouts, loose wires, or the MicroSD card to unseat.
- Method: The avionics sled is fully assembled with the battery secured, powered on and logging. The assembly is then strapped firmly to an orbital sander for 10 seconds, or vigorously shaken by hand, followed by a one meter drop onto a padded surface to simulate deployment shock.
- Expected Result: Passed if the board maintains continuous power, the ESP32 does not reset, and the SD card log shows a continuous stream of data.

Test 5: Simulated Flight Profile (Vacuum Test)
- Objective: Verify that the barometer correctly reads pressure changes, translates them to altitude, and accurately detects the apogee.
- Method: The powered avionics bay is placed inside a vacuum chamber and a partial vacuum is pulled to simulate an ascent to target altitude, and then slowly released to simulate descent.
- Expected Result: Passed if microcontroller logs a smooth, expected altitude curve and correctly flags the apogee.

Test 6: Thermal and Duration Endurance
- Objective: Ensure the system can run for at least an hour when inside an enclosed, unventilated tube.
- Method: The avionics are sealed inside the PETG sled and the outer airframe tube. The system is powered on with the 1500mah main battery and left to log data continuously for a minimum of 1 hour, with 1.5A being drawn from the JST-PH connector.
- Expected Result: Passed if the system logs continuously for 1 hour, the battery drains at an expected rate, and inspection shows no thermal deformation of the PETG or overheating of the buck converter.

# 8 - Remaining project risks

## 8.1- parachute not deploying

A potential cause for concern would be the parachute not deploying. This would lead to a catastrophic error if this were to happen as the rocket would fall and pick up far too much speed if it weren’t being slowed down by the parachute. This would lead to an impact velocity much higher than that predicted and likely result in the rocket failing and breaking completely.
This can be mitigated by researching methods of packing the parachute when it comes time to assemble it and ensure its been packed well and it will definitely open.

Another concern is the rocket failing to separate, leading to failed parachute deployment. To battle this, extensive fit testing of the couplers will be undergone to assure the correct fit between the upper and lower section of the rocket. A tight fit could prevent the sections from coming apart. Whilst a loose fit could lead to early separation which would highly increase the chance of undergoing damage to the rocket.

## 8.2 - Eye bolts

Another potential risk would be the force exerted onto the eye bolts being higher than currently expected. For these calculations, the black powder calculator was used to calculate the force exerted on the bulkhead [3].
Should it exceed this, it would lead to the eye bolt getting ripped out of the bulkhead, meaning the parachute wouldn’t function and the same thing as the parachute not opening would happen in terms of the high impact speed.

## 8.3 - Recovery

High apogee and variable weather conditions could result in the rocket becoming invisible to the naked eye. To combat this, a high visibility parachute is used, and an ExpressLRS receiver and u-blox M10 GPS module will communicate with each other, and send GPS coordinates to a Radiomaster Pocket ground station.

## 8.4 - Total Power Loss

To mitigate the risk of power loss during high vibration events like motor burn and ejection, several hardware and software redundancies have been implemented. A main battery disconnection would power down the microcontroller, risking critical data loss that violates competition guidelines. To prevent this, the main battery is securely mounted to the avionics sled using XT30 connectors, which are accepted in the rocketry community. Additionally, the GPS module operates on an independent backup battery to guarantee location tracking even if the primary system fails. On the software side, flight data is flushed to the microSD card every second to minimize data loss during a power interruption. Through testing it has been verified that if power is temporarily lost and restored, the microcontroller automatically reboots, reinitializes the sensors, and resumes logging in a new flight data file.

# 9 - Next steps

## 9.1 - Lessons learned from completed testing

The testing that has been completed so far comprises the nose cone drop test and the fin impact test.

From the nose cone drop test it was concluded that the nose cone did not have to be completely solid to have a suitable structural strength - this led to the current design being modelled as a 8mm thick hollow shell rather than the previous infilled design. Furthermore, as the destruction of the nose cone when dropped on concrete was along the shoulder connection to the head rather than either part by itself, the additional support provided by being glued to the front body tube should provide additional strength and reduce chances of component failure.

From the fin impact test, it was concluded that the 3mm thick plywood fins would be suitable to survive impact at 9.43m/s when glued into place in the rear assembly and attached to the rear body tube. This means that the fin design does not have to be changed drastically for the final design, allowing the team to focus on other areas of the rocket.

## 9.2 - Future Testing plans

To summarise, the structures testing still to be completed is:

- Body tube compression testing
- Nose cone V2 drop test
- Parachute drop test
- Shock cord force test
- Coupler testing

Body tube compression testing will be done in the structures lab and the tube will rather be loaded with weights to create a stress which exceeds the maximum compressive stress that the tubing will be subjected to (as described in section 6.2) or if available, a section of the tubing will be tested in the UTM’s.

V2 of the nose cone will be tested in the same manner as V1 (see section 6.1).

For the parachute, a drop test with a simulated weight of the rocket will be carried out from a height of 6 floors (20m). To measure the efficacy of the test, a slow motion camera will be used at the bottom to measure the rate of descent against a known distance - this can then be used to test whether the parachute will allow the rocket to descend at a suitable speed.

For the shock cord testing, a mass providing a tensile force equivalent to/ greater than that maximum force experienced will be hung from the shock cord to ensure that it does not snap during separation. Another potential option is using the tensile testing machines in the structures lab if available.

To test the coupler a fit test will be carried out during assembly in which it will be examined whether the coupler very slowly slides out when the rocket is inverted therefore indicating a suitable fit.

## 9.3 - Future Manufacturing

Within the next few weeks, multiple stages of final manufacturing will take place. This includes cutting the body tubing to length and cutting the fin slots using the jig, as well as constructing and inserting the rear assembly that will contain the motor sleeve and the engine mounting brackets. Furthermore, holes will be drilled into the side of the tubing for the launch rails and avionics. For the nose cone, the new design will be 3D printed in the IForge so it can be tested and (if successful) glued into place. Once coupler and sag testing has been completed, the inner coupler will then be glued into position as well as the forward bulkhead and recovery system. With the forward bulkhead then in place, the avionics bay can be fitted into the forward body tube and screwed into place.

On the Avionics side, future manufacturing includes finalizing the physical assembly and integration of the hardware. This begins with completing the 3D-printed avionics bay, which is designed to securely house the main PCB, batteries, and peripheral components. Additionally, the GPS module and apogee display screen will be assembled and mounted to a dedicated perfboard. This perf board will be screwed into the space allocated for it in the avionics bay, above the secondary battery (a 4.35V HiV 1S LiPo). This independent power source ensures the GPS system can continue transmitting coordinates to the ground station even if the main battery disconnects. Once this and some other small tasks such as soldering connectors, mounting and stripping cables, the avionics team will be fully focused on the continued testing of the payload.

# 10 - References

[1]: Charlesworth, P. (n.d.). Model Rocket construction. [online] Model Rocket Construction.doc. Available at: https://ukra.org.uk/wp-content/uploads/2024/07/modelrocketconstruction.pdf.

[2]: Apogee Components, Inc (2020). Aerotech 29mm Single Use Motor - G78G-10. [online] Apogeerockets.com. Available at: https://www.apogeerockets.com/index.php?main_page=product_info&products_id=3 93 (https://www.apogeerockets.com/index.php?main_page=product_info&products_id=393) [Accessed 4 Apr. 2026].

[3]:Cook, J. (n.d.). FFFFg Black Powder Calculator | InsaneRocketry. [online]
www.insanerocketry.com. Available at: https://www.insanerocketry.com/blackpowder.html [Accessed Apr. 8AD].

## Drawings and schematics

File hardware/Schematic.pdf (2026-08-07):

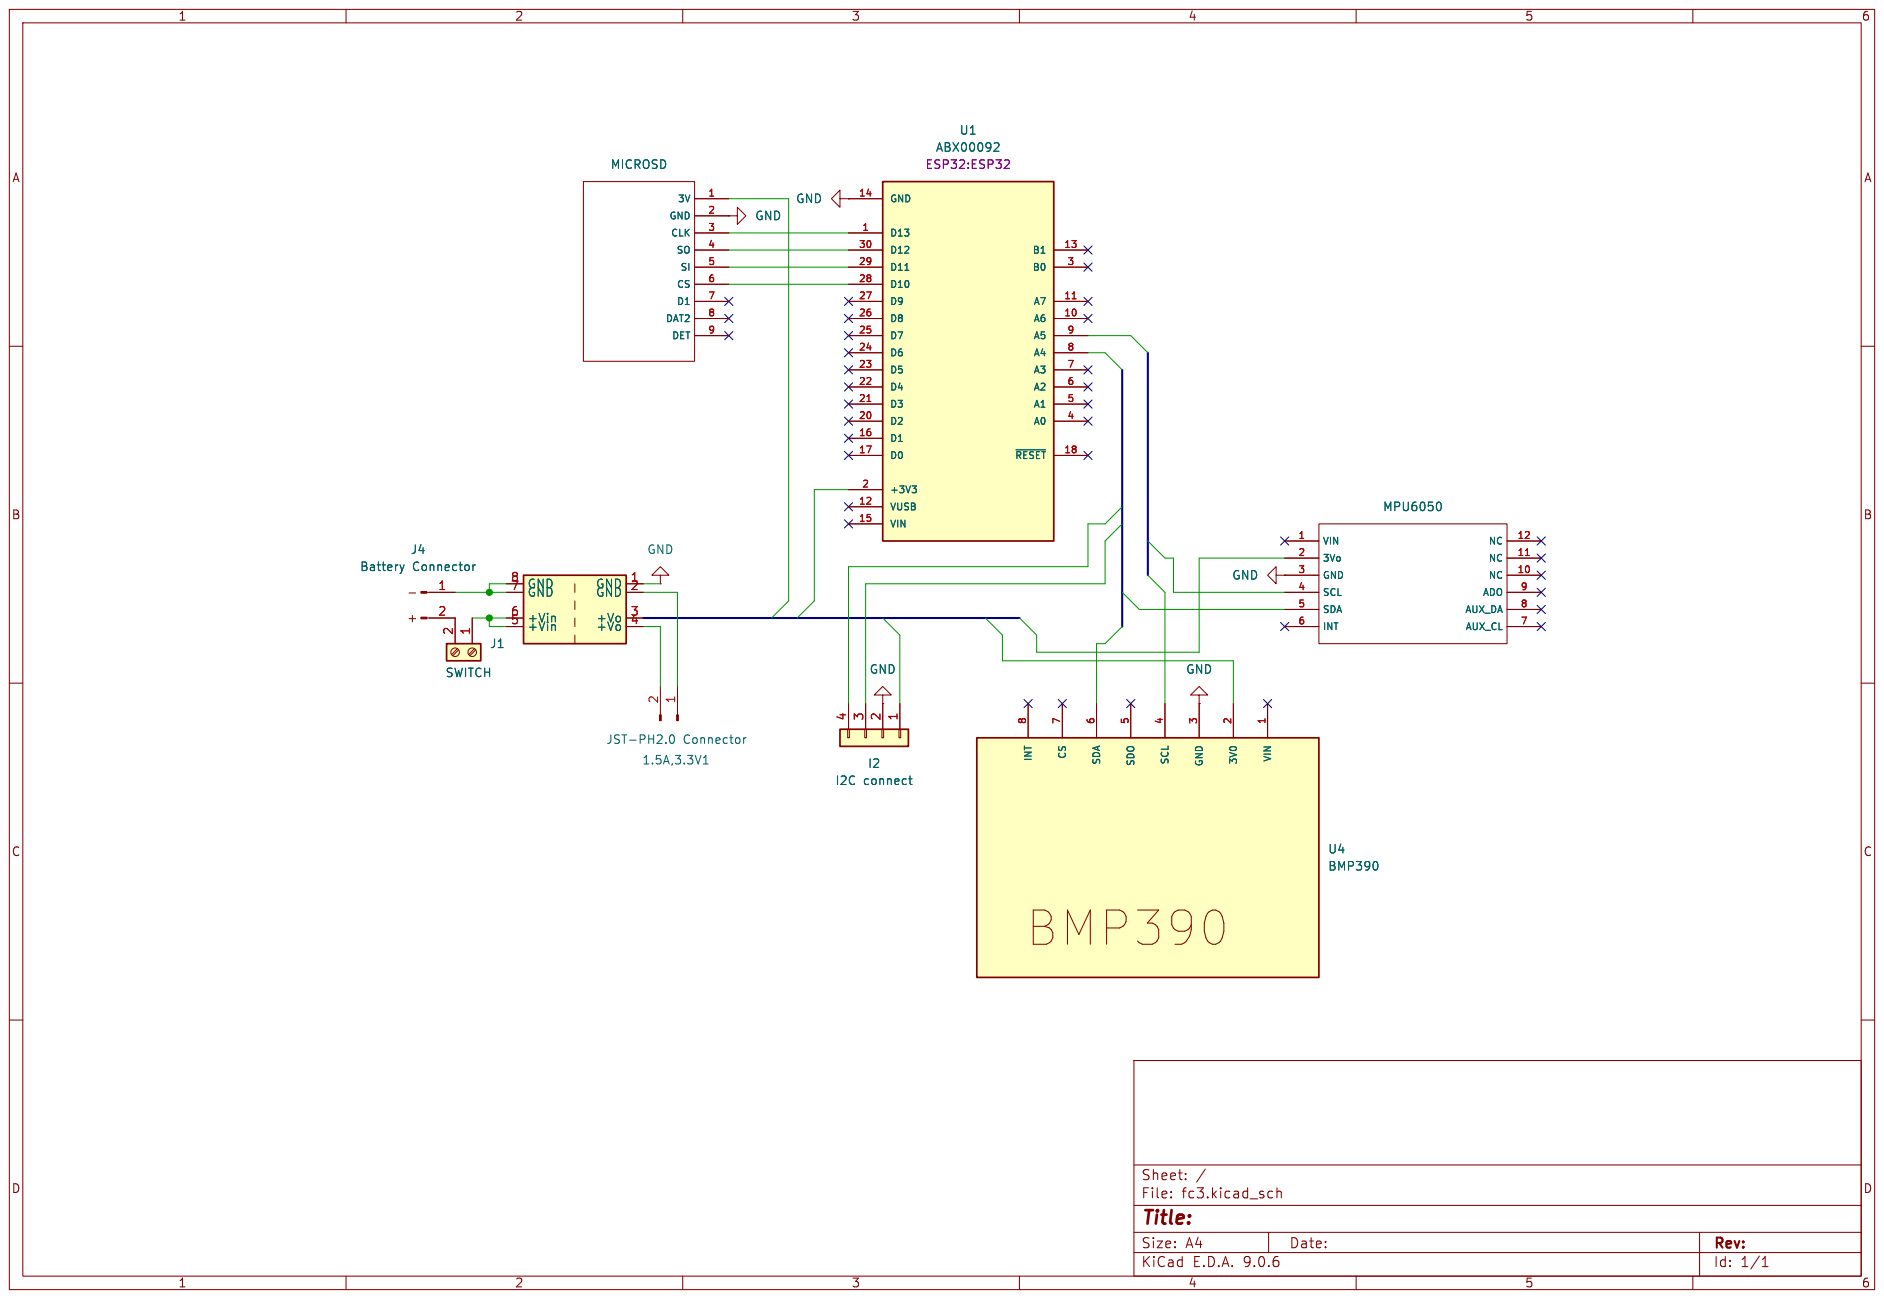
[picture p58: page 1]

Id: 1/1 Title: File: fc3.kicad_sch Sheet: /

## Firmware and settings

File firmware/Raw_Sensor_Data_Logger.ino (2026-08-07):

#include <Wire.h>
#include <SPI.h>
#include <SD.h>
#include <Adafruit_BMP3XX.h>
#include <Adafruit_MPU6050.h>
#include <Adafruit_Sensor.h>
#include <Adafruit_GFX.h>
#include <Adafruit_SSD1306.h>

// --- Configuration Settings ---
const int LOOP_DELAY_MS = 20;        // ~50Hz sample rate
const int DISPLAY_INTERVAL_MS = 200; // ~5Hz screen updates
const int FLUSH_INTERVAL_MS = 500;   // Flush SD card twice a second
const int CHIP_SELECT_PIN = D10; 
const int BATTERY_PIN = A0;      

#define SCREEN_WIDTH 128
#define SCREEN_HEIGHT 32    
#define OLED_RESET    -1 
#define SCREEN_ADDRESS 0x3C 

Adafruit_MPU6050 mpu;
Adafruit_BMP3XX bmp;
Adafruit_SSD1306 display(SCREEN_WIDTH, SCREEN_HEIGHT, &Wire, OLED_RESET);

// Keep the file object globally accessible
File dataFile;
bool sdHealthy = false;

float currentApogee = 0.0;
float groundPressureHPa = 1013.25; 

// --- Timers ---
unsigned long lastDisplayUpdateTime = 0; 
unsigned long lastFlushTime = 0;

// --- Battery Smoothing Variables ---
float smoothedBatteryVoltage = 0.0;
const float BATTERY_ALPHA = 0.05;           // Takes 5% new reading, 95% old history
const float ADC_CALIBRATION_OFFSET = 0.30; // Tweak this offset to match your multimeter
bool isFirstBatteryRead = true;

void setup() {
    Serial.begin(115200); 
    Wire.begin(); 

    pinMode(BATTERY_PIN, INPUT);

    if(!display.begin(SSD1306_SWITCHCAPVCC, SCREEN_ADDRESS)) { while (1); }
    display.clearDisplay();
    display.setTextSize(1);      
    display.setTextColor(SSD1306_WHITE); 
    display.setCursor(0, 0); 
    display.println("BOOTING LOGGERS..."); 
    display.display(); 
    delay(500);

    if (!mpu.begin() || !bmp.begin_I2C()) { while (1); }

    mpu.setAccelerometerRange(MPU6050_RANGE_16_G);
    mpu.setGyroRange(MPU6050_RANGE_500_DEG);
    bmp.setTemperatureOversampling(BMP3_OVERSAMPLING_8X);
    bmp.setPressureOversampling(BMP3_OVERSAMPLING_4X);
    bmp.setIIRFilterCoeff(BMP3_IIR_FILTER_COEFF_3);

    // Warm up the BMP sensor
    for (int i = 0; i < 30; i++) { bmp.performReading(); delay(20); }

    // Calibrate ground pressure for accurate AGL altitude
    float pressureSum = 0;
    int samples = 50;
    for (int i = 0; i < samples; i++) {
        if (bmp.performReading()) { pressureSum += bmp.pressure / 100.0; }
        delay(20);
    }
    groundPressureHPa = pressureSum / samples; 

    // --- SD CARD SETUP ---
    if (SD.begin(CHIP_SELECT_PIN)) {
        dataFile = SD.open("/payload_log.csv", FILE_WRITE);
        if (dataFile) {
            sdHealthy = true;
            if (dataFile.size() == 0) {
                // Header includes the new Pressure and Temp columns
                dataFile.println("TimeMS,Altitude,Pressure,Temp,AccX,AccY,AccZ,GyroX,GyroY,GyroZ,BatteryV");
                dataFile.flush();
            }
        }
    }

    display.clearDisplay();
}

void loop() {
    unsigned long currentTime = millis();

    // Read MPU6050
    sensors_event_t a, g, temp;
    mpu.getEvent(&a, &g, &temp);

    // Read BMP390 (No blocking return, so MPU data logs even if BMP skips a beat)
    bmp.performReading(); 
    
    float relativeAltitude = bmp.readAltitude(groundPressureHPa);
    if (relativeAltitude < 0.0) relativeAltitude = 0.0;

    if (relativeAltitude > currentApogee) {
        currentApogee = relativeAltitude;
    }

    // --- READ AND SMOOTH BATTERY VOLTAGE ---
    int rawADC = analogRead(BATTERY_PIN);
    float measuredVoltage = (rawADC * 3.3) / 4095.0;
    float rawBatteryVoltage = (measuredVoltage * ((10000.0 + 5000.0) / 5000.0)) + ADC_CALIBRATION_OFFSET;

    if (isFirstBatteryRead) {
        smoothedBatteryVoltage = rawBatteryVoltage;
        isFirstBatteryRead = false;
    } else {
        // Exponential Moving Average Filter
        smoothedBatteryVoltage = (BATTERY_ALPHA * rawBatteryVoltage) + ((1.0 - BATTERY_ALPHA) * smoothedBatteryVoltage);
    }

    // --- SD CARD LOGGING ---
    if (sdHealthy && dataFile) {
        dataFile.print(currentTime);            dataFile.print(",");
        dataFile.print(relativeAltitude, 2);    dataFile.print(",");
        
        // Log Pressure (in hPa) and Temperature (in Celsius)
        dataFile.print(bmp.pressure / 100.0, 2);dataFile.print(","); 
        dataFile.print(bmp.temperature, 2);     dataFile.print(",");
        
        dataFile.print(a.acceleration.x, 2);    dataFile.print(",");
        dataFile.print(a.acceleration.y, 2);    dataFile.print(",");
        dataFile.print(a.acceleration.z, 2);    dataFile.print(",");
        dataFile.print(g.gyro.x, 2);            dataFile.print(",");
        dataFile.print(g.gyro.y, 2);            dataFile.print(",");
        dataFile.print(g.gyro.z, 2);            dataFile.print(",");
        dataFile.println(smoothedBatteryVoltage, 2);     
        
        // Non-Blocking SD Flush (runs twice a second)
        if (currentTime - lastFlushTime >= FLUSH_INTERVAL_MS) {
            dataFile.flush();
            lastFlushTime = currentTime;
        }
    }

    // --- OLED DISPLAY ---
    if (currentTime - lastDisplayUpdateTime >= DISPLAY_INTERVAL_MS) {
        lastDisplayUpdateTime = currentTime;

        display.clearDisplay(); 
        display.setTextColor(SSD1306_WHITE);
        display.setTextSize(1);
        display.setCursor(0, 0);
        display.print("MAX APOGEE");

        // Display the perfectly smooth battery voltage
        display.setCursor(90, 0);
        display.print(smoothedBatteryVoltage, 1);
        display.print("V");

        display.setTextSize(2); 
        display.setCursor(0, 15);
        display.print(currentApogee, 1);
        display.print(" m");

        display.display(); 
    }

    delay(LOOP_DELAY_MS);
}

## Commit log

2026-08-23 Rename IMG_3842.jpeg to PCB Assembly.jpeg
2026-08-23 Rename IMG_3489.JPG to Kicad Design.JPG
2026-08-23 Rename IMG_3820.jpeg to voltage monitoring.jpeg
2026-08-23 Rename IMG_3487.jpeg to breadboard prototype.jpeg
2026-08-23 Rename breadboard prototype.jpeg to breadboard_prototype.jpeg
